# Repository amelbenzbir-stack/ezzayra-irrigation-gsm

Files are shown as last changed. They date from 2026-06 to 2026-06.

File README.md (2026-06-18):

# Ezzayra — Télégestion d'irrigation par SMS/GSM

> Stage d'ingénieur — Informatique Industrielle et Automatique (3e année, INSAT)
> **Entreprise :** EZZAYRA SOLUTIONS, Tunis
> **Étudiante :** Amal Ben Zbir
> **Durée :** 7 semaines — 2025-2026

---

## Contexte

EZZAYRA SOLUTIONS est une entreprise tunisienne spécialisée dans la digitalisation des chaînes de valeur agricoles. Sa plateforme **AgriManager** couvre la gestion parcellaire, le suivi satellitaire et le pilotage de l'irrigation pour plus de 60 000 hectares en Tunisie, Côte d'Ivoire et Espagne.

Sur le terrain, de nombreuses exploitations sont éloignées, sans couverture Internet fiable, mais couvertes par le réseau **GSM 2G**. Ce projet vise à concevoir un système embarqué autonome permettant de commander à distance, par simple SMS, les équipements d'irrigation d'une exploitation agricole.

---

## Objectif du projet

Concevoir, développer et tester un prototype fonctionnel de **carte de commande à distance** comprenant :

- Un microcontrôleur **Arduino Mega 2560** (prototype V1)
- Un module relais (4 canaux pour les électrovannes + 1 canal dédié à la motopompe)
- Un **modem GSM SIM800L** pour la réception et l'envoi de SMS
- Un afficheur **LCD 16x2** pour le diagnostic local sur site
- Un **firmware robuste** implémentant un protocole de commandes SMS sécurisé, avec programmation horaire automatique et alertes

---

## Architecture du système

```
Agriculteur (SMS)
      │
      ▼
Réseau GSM 2G
      │
      ▼
Modem SIM800L ──(UART)──► Arduino Mega 2560 ──► LCD 16x2 (diagnostic local)
                                │
                           GPIO (5V logique)
                                │
                      Modules relais (4 + 1 canaux)
                      /        |        \         \
                 Vanne 1   Vanne 2..4   Motopompe
                 (12/24V)   (12/24V)    (220V via contacteur)
```

---

## Protocole de commandes SMS

| Commande SMS | Action | Réponse |
|---|---|---|
| `#OUVRIR Vx` | Ouvrir l'électrovanne n°x (1 à 4) | `Vanne x ouverte - hh:mm:ss` |
| `#FERMER Vx` | Fermer l'électrovanne n°x | `Vanne x fermee - hh:mm:ss` |
| `#POMPE ON` | Démarrer la motopompe | `Pompe demarree - hh:mm:ss` |
| `#POMPE OFF` | Arrêter la motopompe | `Pompe arretee - hh:mm:ss` |
| `#PROG Vx hh:mm durée` | Planifier l'ouverture automatique d'une vanne | Confirmation + déclenchement/fermeture automatiques à l'heure prévue |
| `#PROG Vx OFF` | Annuler une programmation existante | `Programmation Vx annulee` |
| `#ETAT` | Rapport d'état complet | Vannes, pompe, signal GSM, programmations actives, horodatage |
| `#STOP` puis `#STOP CONFIRM` | Arrêt d'urgence à double confirmation (60s) | `ARRET URGENCE execute` |
| `#AIDE` | Liste des commandes disponibles | Liste complète |

---

## Fonctionnalités de sécurité

- **Liste blanche** : seuls les numéros pré-enregistrés peuvent commander le système ; toute autre tentative est ignorée et journalisée
- **État sûr au démarrage** : au redémarrage, toutes les sorties sont mises à l'état fermé
- **Watchdog logiciel** : réinitialisation automatique en cas de blocage supérieur à 30 secondes
- **Arrêt d'urgence à double confirmation** : la commande `#STOP` exige une confirmation explicite dans les 60 secondes
- **Protection pompe** : arrêt automatique après 1 heure de fonctionnement continu, avec alerte
- **Alerte signal GSM faible** : vérification périodique (10 min) du niveau de signal réseau
- **Isolation galvanique** : relais opto-isolés séparant la logique de commande des circuits de puissance

---

## Stack technique

| Composant | Technologie |
|---|---|
| Microcontrôleur | Arduino Mega 2560 (C/C++) |
| Communication GSM | SIM800L — commandes AT (`AT+CMGF`, `AT+CCLK?`, `AT+CSQ`...) |
| Affichage local | LCD 16x2 (bus 4 bits) |
| Simulation matérielle | Proteus 8 Professional |
| Schémas électriques | KiCad |
| Versioning | Git / GitHub |

---

## Structure du dépôt

```
ezzayra-irrigation-gsm/
├── firmware/
│   └── firmware_proteus.ino   ← Firmware complet (FSM, #PROG, LCD, sécurité)
│                                  Bascule production/démo via la constante
│                                  MODE_DEMO en tête de fichier :
│                                    - false → mode réel (Serial1 + modem SIM800L)
│                                    - true  → mode démonstration (lecture clavier
│                                              directe sur Serial + horloge simulée
│                                              accélérée, utilisé pour la vidéo)
├── simulation/
│   ├── simulation_ezzayra.pdsprj   ← Projet de simulation Proteus complet
│   └── firmware_proteus.ino.hex    ← Firmware compilé chargé dans la simulation
├── schemas/                    ← Schémas électriques KiCad
├── docs/
│   ├── Cahier_des_charges_v2.pdf
│   └── BOM_Ezzayra.pdf
└── README.md
```

---

## Mode de démonstration (simulation Proteus)

Le firmware intègre un **mode démonstration** activable par une simple constante (`MODE_DEMO`), pensé pour permettre une démonstration fluide et fiable du système sans dépendre d'un pont logiciel externe entre un modem GSM simulé et Proteus :

- Les commandes sont saisies directement dans le moniteur série Arduino (`Serial`), comme si elles étaient déjà des SMS décodés (ex. taper `#OUVRIR V1` directement)
- Une **horloge simulée accélérée** (1 minute simulée toutes les 3 secondes réelles) permet de démontrer la programmation horaire automatique (`#PROG`) sans attendre une vraie journée
- La commande `#HEURE hh:mm` permet de forcer l'horloge simulée à une valeur précise, utile pour caler une démonstration filmée

Cette approche a été retenue après plusieurs tentatives de pont série entre un simulateur externe et Proteus (COMPIM, ports série virtuels, automatisation de saisie), qui n'ont pas abouti à une solution suffisamment fiable pour une démonstration filmée.

---

## Planning du stage

| Phase | Contenu | Durée |
|---|---|---|
| P1 | Étude bibliographique, commandes AT, état de l'art | Semaine 1 |
| P2 | Conception schéma électrique, protocole SMS, BOM | Semaines 2-3 |
| P3 | Développement firmware C++ (FSM, relais, watchdog, #PROG) | Semaines 3-5 |
| P4 | Simulation Proteus, tests unitaires et de robustesse | Semaine 6 |
| P5 | Rapport, documentation, démonstration vidéo | Semaine 7 |

---

## Livrables

- [x] Cahier des charges et étude comparative des plateformes
- [x] Schéma électrique complet (KiCad) + BOM avec coûts
- [x] Firmware C++ commenté et versionné (commandes complètes + `#PROG` fonctionnel)
- [x] Simulation Proteus complète (relais, LCD, mode démonstration)
- [ ] Rapport de tests formalisé (scénario validé, mise en fichier en cours)
- [ ] Manuel d'installation destiné à l'agriculteur
- [ ] Rapport de stage complet
- [ ] Vidéo de démonstration

---

## Tester la simulation

### Prérequis
- Proteus 8 Professional
- Bibliothèque de modules relais Arduino installée (LIB + MODELS)

### Lancer la simulation
1. Ouvrir `simulation/simulation_ezzayra.pdsprj` dans Proteus
2. Lancer la simulation (▶)
3. Ouvrir le Virtual Terminal connecté sur Serial0
4. Taper directement une commande, par exemple `#OUVRIR V1`, puis Entrée

### Tester la programmation horaire automatique
```
#HEURE 06:25
#PROG V1 06:30 2
```
Puis observer le LCD : la vanne s'ouvre automatiquement à l'heure simulée programmée, et se referme après la durée prévue, sans intervention supplémentaire.

---

## Encadrement

- **Entreprise :** EZZAYRA SOLUTIONS — Tunis
- **Encadrant technique :** M. Yasser Bououd (CEO)
- **Encadrant académique :** INSAT — Informatique Industrielle et Automatique

---

*Stage réalisé dans le cadre de l'écosystème AgriManager — EZZAYRA SOLUTIONS, Tunis, 2025-2026*

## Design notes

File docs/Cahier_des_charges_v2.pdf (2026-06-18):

EZZAYRA SOLUTIONS

Tunis, Tunisie

Document technique interne — EZZAYRA SOLUTIONS

## CAHIER DES CHARGES

## Système de Télégestion de l’Irrigation Agricole

## par Commandes SMS sur Réseau GSM

Projet intégré à la plateforme AgriManager — EZZAYRA SOLUTIONS

Préparé par : | Amal Ben Zbir
Formation : | Ingénieure 3e année — INSAT Tunis
Spécialité : | Informatique Industrielle et Automatique
Encadrant : | M. Yasser Bououd, CEO
Durée : | 7 semaines

Année universitaire : 2025 – 2026

Date : | Juin 2026

EZZAYRA SOLUTIONS — Juin 2026

# Table des Matières

Introduction Générale | 3
1 Contexte Général et Analyse de la Problématique | 4
2 Objectifs, Périmètre et Parties Prenantes | 6
3 Exigences du Système | 8
4 Architecture Technique du Système | 11
5 Protocole de Communication SMS | 15
6 Plan de Réalisation et Livrables | 17
Conclusion Générale | 19

# Liste des Figures

4.1 Architecture fonctionnelle du système de télégestion par SMS/GSM . . 12

# Liste des Tableaux

2.1 Objectifs spécifiques du projet | | 6
2.2 Parties prenantes du projet | | 7
3.1 Exigences fonctionnelles | | 8
3.2 Exigences de sécurité | | 9
3.3 Exigences non fonctionnelles | | 10
4.1 Comparaison des plateformes microcontrôleurs | | 11
4.2 Description des blocs fonctionnels | | 13
4.3 États de la machine à états finis du firmware | | 14
5.1 Protocole de commandes SMS | | 16
5.2 Alertes automatiques | | 16
6.1 Planning prévisionnel du stage | | 17
6.2 Liste des livrables | | 18
6.3 Critères de validation du projet | | 18

# Introduction Générale

L’agriculture tunisienne traverse une phase de mutation profonde, portée par l’essor des technologies numériques et la nécessité d’optimiser l’utilisation des ressources naturelles, notamment l’eau. Dans ce contexte, la gestion intelligente de l’irrigation représente un levier stratégique pour améliorer la productivité agricole et réduire les coûts d’exploitation.

Ce document constitue le cahier des charges du projet mené au sein de la société EZZAYRA SOLUTIONS, acteur tunisien de l’agriculture numérique. Le projet vise à concevoir un dispositif électronique embarqué permettant la commande à distance d’équipements d’irrigation par simple message SMS, en s’appuyant uniquement sur l’infrastructure GSM 2G disponible dans les zones rurales.

Le présent cahier des charges a pour objectifs de définir rigoureusement les besoins du système, de préciser les contraintes techniques et opérationnelles, de justifier les choix d’architecture et de fournir un cadre de référence pour l’ensemble des phases de réalisation.

Ce document est structuré en six chapitres :

- Chapitre 1 — Contexte général et analyse de la problématique
- Chapitre 2 — Objectifs, périmètre et parties prenantes
- Chapitre 3 — Exigences fonctionnelles et non fonctionnelles
- Chapitre 4 — Architecture technique du système
- Chapitre 5 — Protocole de communication SMS
- Chapitre 6 — Plan de réalisation, livrables et validation

## Chapitre 1

# Contexte Général et Analyse de la Problématique

### 1.1 Présentation de l’entreprise EZZAYRA SOLUTIONS

EZZAYRA SOLUTIONS est une entreprise tunisienne spécialisée dans les solutions numériques pour l’agriculture. Elle développe la plateforme AgriManager, déployée sur plus de 60 000 hectares en Tunisie, en Côte d’Ivoire et en Espagne, couvrant la gestion des parcelles, la planification agricole et le pilotage de l’irrigation.

### 1.2 Diagnostic de la situation actuelle

L’analyse des pratiques d’irrigation sur les exploitations agricoles tunisiennes, en particulier dans les régions centre et sud, révèle plusieurs dysfonctionnements récurrents liés à l’absence de systèmes de commande à distance.

Les exploitations concernées se caractérisent par leur éloignement géographique, l’absence de connexion Internet stable et la dépendance totale à des interventions physiques pour toute opération sur les équipements d’irrigation. Cette réalité engendre des surcoûts significatifs en termes de déplacements, une réactivité insuffisante en cas d’anomalie et une gestion approximative des plages d’arrosage.

### 1.3 Problématique

Comment concevoir un système embarqué autonome permettant à un agriculteur de piloter ses équipements d’irrigation depuis son téléphone mobile, sans nécessiter de connexion Internet, tout en garantissant la sécurité, la fiabilité et la simplicité d’utilisation du dispositif ?

### 1.4 Solution envisagée

Cahier des Charges — Carte de commande GSM/SMS INSAT / EZZAYRA SOLUTIONS

La solution proposée repose sur le réseau GSM 2G, dont la couverture est quasi-totale sur le territoire tunisien, y compris dans les zones rurales isolées. Une carte électronique embarquée, installée sur le site agricole, assurera la réception de commandes transmises par SMS, leur traitement sécurisé et l’activation des actionneurs correspondants. Chaque commande donnera lieu à un accusé de réception automatique, et le système sera capable d’émettre des alertes en cas d’anomalie.

EZZAYRA SOLUTIONS | 2025–2026 | 5

## Chapitre 2

# Objectifs, Périmètre et Parties Prenantes

### 2.1 Objectif général

Concevoir, développer et valider un prototype fonctionnel d’un système de télégestion de l’irrigation par SMS/GSM, destiné à être intégré à la plateforme AgriManager d’EZZAYRA SOLUTIONS dans une phase ultérieure.

### 2.2 Objectifs spécifiques

Table 2.1: Objectifs spécifiques du projet

Réf. | Objectif | Détail
OS-1 | Étude et analyse | Étudier les solutions existantes et établir un état de l’art
OS-2 | Conception matérielle | Produire le schéma électrique complet sous KiCad
OS-3 | Développement firmware | Implémenter le firmware en C++ sur microcontrôleur Arduino
OS-4 | Protocole SMS | Définir et implémenter un protocole de commandes sécurisé
OS-5 | Simulation | Valider le système en environnement de simulation Proteus, avec un mode de démonstration intégré au firmware
OS-6 | Tests | Réaliser les tests unitaires et de robustesse du système
OS-7 | Documentation | Produire l’ensemble des livrables techniques et documentaires

### 2.3 Périmètre du projet

### 2.3.1 Inclus dans le périmètre

- Schéma électrique complet (alimentation, protection, isolation, commande)
- Firmware Arduino Mega 2560 avec machine à états et protocole SMS
- Simulation Proteus du circuit complet (microcontrôleur, modules relais, LCD) avec mode de démonstration intégré au firmware pour la validation fonctionnelle
- Tests fonctionnels et de robustesse
- Documentation : cahier des charges, BOM, manuel utilisateur, rapport de stage

### 2.3.2 Hors périmètre

- Intégration à la plateforme AgriManager (phase ultérieure)
- Application mobile dédiée
- Communication via réseau 4G ou Internet

### 2.4 Parties prenantes

Table 2.2: Parties prenantes du projet

Partie prenante | Rôle | Intérêt
Amal Ben Zbir | Étudiante / Développeuse | Réalisation du projet de stage
M. Yasser Bououd | Encadrant entreprise / CEO | Validation technique et fonctionnelle
Encadrant INSAT | Encadrant académique | Suivi pédagogique et évaluation
Agriculteurs | Utilisateurs finaux | Utilisation quotidienne du système
EZZAYRA SOLUTIONS | Commanditaire | Intégration future à AgriManager

## Chapitre 3

# Exigences du Système

### 3.1 Exigences fonctionnelles

Table 3.1: Exigences fonctionnelles

ID | Intitulé | Description | Prior.
EF-01 | Réception SMS | Décoder les messages SMS entrants via le modem SIM800L | P1
EF-02 | Commande vannes | Ouvrir et fermer indépendamment jusqu’à 4 électrovannes | P1
EF-03 | Commande pompe | Démarrer et arrêter la motopompe | P1
EF-04 | Accusé de réception | Envoyer un SMS de confirmation après chaque commande | P1
EF-05 | Rapport d’état | Fournir l’état complet des sorties, le signal GSM et l’horodatage | P1
EF-06 | Arrêt d’urgence | Couper toutes les sorties en réponse à la commande #STOP | P1
EF-07 | Horodatage | Inclure la date et l’heure dans chaque réponse SMS | P2
EF-08 | Programmation | Planifier l’ouverture d’une vanne à une heure donnée | P2
EF-09 | Alerte démarrage | Notifier les numéros autorisés lors de chaque redémarrage | P1
EF-10 | Protection pompe | Arrêter la pompe et alerter après dépassement de la durée maximale | P1
EF-11 | Alerte GSM | Signaler un niveau de signal GSM insuffisant | P2
EF-12 | Aide utilisateur | Retourner la liste des commandes disponibles sur demande | P3
P1 : Prioritaire | P2 : Souhaitable | P3 : Optionnel

Note relative à EF-08 (programmation horaire) : la précision du déclenchement dépend de la fréquence d’interrogation de l’horloge réseau GSM par le firmware (60 secondes), ce qui induit un écart possible de l’ordre de ±1 minute par rapport à l’heure programmée. Cette limite, acceptable pour un usage agricole, sera levée en V2 par l’ajout d’un module RTC externe DS3231 garantissant une précision à la seconde, indépendante du réseau GSM.

### 3.2 Exigences de sécurité

Table 3.2: Exigences de sécurité

ID | Intitulé | Description
ES-01 | Contrôle d’accès | Seuls les numéros de téléphone pré-enregistrés peuvent envoyer des commandes
ES-02 | Rejet des intrus | Toute commande d’un numéro non autorisé est ignorée sans réponse
ES-03 | Journalisation | Les tentatives non autorisées sont comptabilisées et signalées à l’administrateur
ES-04 | État sûr au démarrage | Au démarrage ou après toute réinitialisation, toutes les sorties sont à l’état fermé
ES-05 | Double confirmation | La commande d’arrêt d’urgence requiert une confirmation explicite dans les 60 secondes
ES-06 | Surveillance système | Un mécanisme de watchdog détecte et corrige tout blocage du programme
ES-07 | Protection électrique | Une diode de protection prévient les dommages en cas d’inversion de polarité
ES-08 | Isolation galvanique | Les relais opto-isolés séparent physiquement la logique de commande et les circuits de puissance

### 3.3 Exigences non fonctionnelles

Table 3.3: Exigences non fonctionnelles

ID | Catégorie | Description
ENF-01 | Performance | Le délai entre la réception du SMS et l’exécution de la commande ne doit pas excéder 10 secondes
ENF-02 | Disponibilité | Le système doit fonctionner de manière continue, 24h/24 et 7j/7, sans intervention humaine
ENF-03 | Alimentation | L’alimentation principale est de 12 V DC, compatible batterie et panneau solaire
ENF-04 | Consommation | La consommation en veille doit être inférieure à 200 mA pour permettre une alimentation solaire
ENF-05 | Température | Le système doit fonctionner correctement entre −10 ◦C et +60 ◦C
ENF-06 | Protection | L’installation doit être réalisée dans un boîtier étanche de classe IP65 minimum
ENF-07 | Maintenabilité | Le code source doit être commenté, structuré et versionné sur un dépôt Git
ENF-08 | Coût | Le coût total en composants ne doit pas excéder 250 DT hors option solaire
ENF-09 | Connectivité | Le système doit opérer uniquement via le réseau GSM 2G, sans dépendance à Internet
ENF-10 | Fiabilité | Le taux de succès de traitement des commandes SMS valides doit dépasser 99 %

## Chapitre 4

# Architecture Technique du Système

### 4.1 Étude comparative des plateformes microcontrôleurs

Trois familles de microcontrôleurs ont été évaluées selon des critères adaptés aux contraintes du projet : déploiement sur site isolé, alimentation autonome, développement rapide et fiabilité à long terme.

Table 4.1: Comparaison des plateformes microcontrôleurs

Critère | Arduino Mega 2560 | STM32 Nucleo | Raspberry Pi 4
Démarrage | Immédiat | Immédiat | 25–35 s (OS)
Consommation veille | ≈50 mA | ≈30 mA | ≈600 mA
Complexité dev. | Faible | Moyenne | Élevée
Fiabilité terrain | Très bonne | Excellente | Moyenne
Ports UART | 4 matériels | 3 matériels | 1 matériel
Écosystème | Très large | Large | Large
Coût approximatif | 63 DT | 135 DT | 250 DT
Verdict | Prototype V1 | V2 industrielle | Non retenu

L’Arduino Mega 2560 est sélectionné pour le prototype V1 au regard de quatre facteurs déterminants : son démarrage instantané sans système d’exploitation, sa consommation faible compatible avec une alimentation solaire, ses quatre ports UART matériels facilitant la communication avec le modem GSM, et son coût sensiblement inférieur aux alternatives.

### 4.2 Architecture matérielle

### 4.2.1 Schéma fonctionnel du système

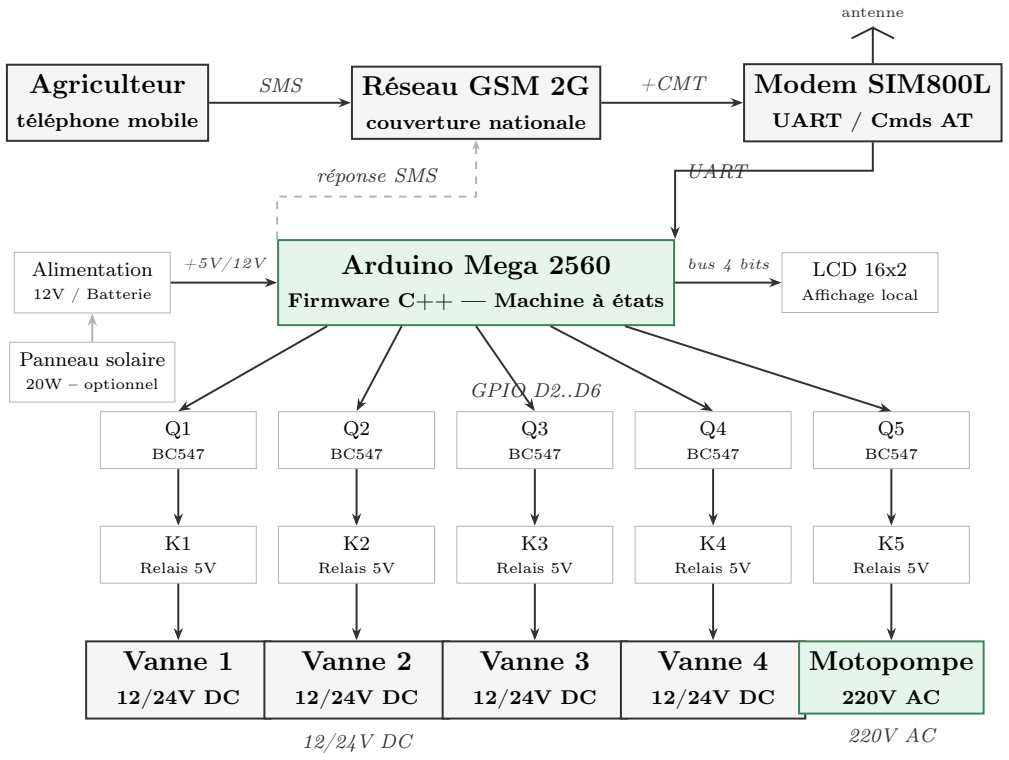
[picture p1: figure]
Agriculteur; téléphone mobile; Réseau GSM 2G; couverture nationale; Modem SIM800L; UART / Cmds AT; antenne; SMS; +CMT; Arduino Mega 2560; Firmware C++ — Machine à états; réponse SMS; UART; Alimentation; 12V / Batterie; Panneau solaire; 20W – optionnel; LCD 16x2; Affichage local; bus 4 bits; GPIO D2..D6; Relais 5V; Vanne 1; Vanne 2; Vanne 3; Vanne 4; Motopompe

Figure 4.1: Architecture fonctionnelle du système de télégestion par SMS/GSM

### 4.2.2 Description des blocs fonctionnels

Table 4.2: Description des blocs fonctionnels

Bloc | Composant | Fonction
Microcontrôleur | Arduino Mega 2560 | Cerveau du système : interprète les commandes SMS, pilote les sorties et assure la sécurité via une machine à états finis
Modem GSM | SIM800L V2.0 | Émission et réception de SMS via le réseau GSM 2G. Fournit l’heure réseau via la commande AT AT+CCLK?
Horodatage | AT+CCLK? (SIM800L) | L’heure est extraite du réseau GSM via la commande AT AT+CCLK? du modem. Cette approche est suffisante pour le prototype V1. L’ajout d’un module RTC externe DS3231 est prévu en V2 pour garantir l’horodatage lors des coupures réseau
Régulation 5 V | L7805 + C 1000 µF | Régulateur linéaire 12 V → 5 V pour le prototype V1. Le condensateur 1000 µF en sortie absorbe les pics de courant du SIM800L (jusqu’à 2 A sur de courtes durées). Pour la version industrielle V2, un convertisseur DC-DC Buck LM2596 (3 A, rendement 90 %) sera préféré pour réduire l’échauffement
Adaptation niveaux | Diviseur R6/R7 | Conversion 5 V → 3,3 V sur la ligne TX Arduino → SIM800L
Drivers transistors | BC547 + 1 kΩ (x5) | Amplification du signal GPIO (5 mA) pour commander les bobines des relais (100 mA)
Relais | G5V-2 5 V (x5) | Isolation galvanique entre logique 5 V et circuits de puissance (12/24 V DC – 220 V AC)
Protection entrée | Diode 1N4007 | Protection contre l’inversion de polarité à l’entrée 12 V
Affichage local | LCD 16x2 | Affichage en temps réel de l’état des vannes, de la pompe, des alertes et de l’heure réseau, pour la maintenance et le diagnostic sur site

### 4.3 Architecture logicielle

Le firmware est construit autour d’une machine à états finis (FSM) qui garantit un comportement déterministe et une gestion robuste des cas limites.

Table 4.3: États de la machine à états finis du firmware

État | Désignation | Comportement
S0 | VEILLE | Surveillance permanente du port série GSM en attente d’un événement
S1 | SMS_RECU | Détection d’une notification +CMT et lecture du contenu du message
S2 | VERIFICATION | Contrôle du numéro expéditeur par rapport à la liste blanche
S3 | EXECUTION | Interprétation et exécution de la commande reçue
S4 | REPONSE | Envoi du SMS de confirmation horodaté à l’expéditeur
S5 | ALERTE | Émission d’un SMS d’alerte automatique vers les numéros autorisés

## Chapitre 5

# Protocole de Communication SMS

### 5.1 Format général des commandes

L’ensemble des commandes respecte la syntaxe suivante :

#<COMMANDE> [PARAMÈTRE1] [PARAMÈTRE2]

Les commandes sont insensibles à la casse et converties en majuscules avant traitement. Tout message ne respectant pas ce format est ignoré et journalisé.

### 5.2 Tableau des commandes SMS

Table 5.1: Protocole de commandes SMS

Commande | Action déclenchée | Réponse SMS
#OUVRIR Vx | Ouverture de la vanne x | Vanne x ouverte –-hh:mm:ss

#FERMER Vx | Fermeture de la vanne x | Vanne x fermee –-hh:mm:ss

#POMPE ON | Démarrage de la pompe | Pompe demarree –-hh:mm:ss

#POMPE OFF | Arrêt de la pompe | Pompe arretee –-hh:mm:ss

#ETAT | Rapport d’état du système | État V1..V4, pompe, signal GSM, heure

#PROG Vx hh:mm dur | Ouverture planifiée d’une vanne | Prog Vx enregistree – OK

#PROG Vx OFF | Annulation d’une programmation existante | Programmation Vx annulee

#STOP | Demande d’arrêt d’urgence | Confirmez avec #STOP CONFIRM

#STOP CONFIRM | Arrêt d’urgence confirmé | ARRET URGENCE execute –-hh:mm:ss

#AIDE | Liste des commandes | Liste complète par SMS

### 5.3 Alertes automatiques du système

Table 5.2: Alertes automatiques

Événement | Message SMS envoyé
Redémarrage du système | Notification de remise en service et confirmation de l’état sûr
Durée maximale pompe atteinte | Alerte arrêt automatique avec horodatage
Signal GSM faible (CSQ < 10) | Alerte avec niveau de signal mesuré
3 tentatives non autorisées | Alerte sécurité avec numéro de l’expéditeur suspect

## Chapitre 6

# Plan de Réalisation et Livrables

### 6.1 Planning prévisionnel

Table 6.1: Planning prévisionnel du stage

Phase | Intitulé | Tâches principales | Durée
P1 | Étude et état de l’art | Analyse de l’existant, commandes AT GSM, documentation | S1
P2 | Conception | Schéma KiCad, nomenclature BOM, protocole SMS | S2–S3
P3 | Développement firmware | FSM, commandes AT, relais, watchdog | S3–S5
P4 | Tests et simulation | Simulation Proteus, tests unitaires, tests de robustesse | S6
P5 | Documentation | Rapport, manuel utilisateur, démonstration | S7

### 6.2 Livrables du projet

Table 6.2: Liste des livrables

N° | Livrable | Description | Phase
L1 | Cahier des charges | Document de référence du projet (présent document) | P1
L2 | Schéma électrique | Fichier KiCad complet exporté en PDF | P2
L3 | BOM | Nomenclature avec références et prix en DT | P2
L4 | Firmware C++ | Code source commenté et versionné sur GitHub | P3
L5 | Simulation Proteus | Schéma de simulation complet et mode de démonstration intégré au firmware | P4
L6 | Rapport de tests | Résultats des tests unitaires et de robustesse | P4
L7 | Manuel utilisateur | Guide simplifié destiné à l’agriculteur | P5
L8 | Rapport de stage | Document final complet | P5

### 6.3 Critères d’acceptation

Table 6.3: Critères de validation du projet

ID | Critère | Condition de validation
CA-01 | Délai de traitement | Inférieur à 10 secondes entre la réception du SMS et l’exécution
CA-02 | Contrôle d’accès | 100 % des commandes non autorisées rejetées sans réponse
CA-03 | Résilience | Redémarrage en état sûr après toute coupure d’alimentation
CA-04 | Watchdog | Réinitialisation automatique en cas de blocage supérieur à 30 secondes
CA-05 | Protection pompe | Arrêt automatique après 1 heure de fonctionnement continu
CA-06 | Accusés de réception | 100 % des commandes valides génèrent un SMS de confirmation
CA-07 | Couverture fonctionnelle | Les 9 commandes du protocole fonctionnent sans erreur

# Conclusion Générale

Ce cahier des charges a permis de formaliser l’ensemble des aspects du projet de télégestion de l’irrigation agricole par SMS/GSM mené au sein d’EZZAYRA SOLUTIONS dans le cadre du stage de fin de 3e année à l’INSAT.

L’analyse de la situation de départ a mis en évidence un besoin concret et pertinent : permettre aux agriculteurs d’exploitations isolées de piloter leurs équipements d’irrigation à distance, sans nécessiter de connexion Internet, à partir de leur téléphone mobile ordinaire. La solution retenue, basée sur un Arduino Mega 2560 couplé à un modem SIM800L et un réseau de relais opto-isolés, répond de manière adaptée à l’ensemble des contraintes identifiées.

Les exigences fonctionnelles, de sécurité et non fonctionnelles ont été rigoureusement définies, et les critères d’acceptation établis permettront une validation objective du système à l’issue de la phase de tests. Ce document servira de référence commune entre l’étudiante, l’encadrant industriel et l’encadrant académique tout au long de la réalisation du projet.

La réussite de ce projet ouvrira la voie à une intégration du module de commande au sein de la plateforme AgriManager, contribuant ainsi à la stratégie de digitalisation de l’agriculture tunisienne portée par EZZAYRA SOLUTIONS.

Évolutions envisagées pour la version V2 : le choix de l’Arduino Mega 2560, doté de quatre ports UART matériels, permettra de remplacer facilement le modem SIM800L (GSM 2G) par un module SIM7600 (4G/LTE) sans réécriture du firmware, anticipant ainsi l’obsolescence progressive du réseau 2G. Par ailleurs, le renforcement de la sécurité par l’ajout d’un code PIN dans les commandes SMS (exemple : #OUVRIR V1 1234) permettra de prévenir les risques d’usurpation d’identité, pour une utilisation en environnement industriel sensible.

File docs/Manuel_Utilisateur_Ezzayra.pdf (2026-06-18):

Manuel d'utilisation — Système EZZAYRA

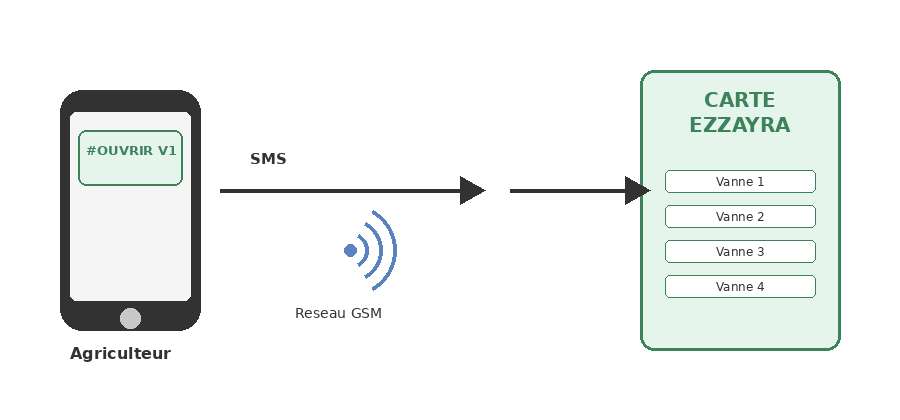
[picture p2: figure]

EZZAYRA SOLUTIONS — Page 1

## EZZAYRA SOLUTIONS

Tunis, Tunisie

# MANUEL D'UTILISATION

## Système de commande d'irrigation par SMS

Guide simple pour piloter vos vannes et votre pompe depuis votre téléphone

EZZAYRA SOLUTIONS — Page 2

## Bienvenue

Ce guide vous explique, de façon simple, comment commander vos vannes d'irrigation et votre pompe à l'aide de votre téléphone portable, par simple message (SMS).
Vous n'avez besoin d'aucune connexion Internet. Le système fonctionne avec le réseau de téléphone mobile classique, le même que celui que vous utilisez pour appeler ou envoyer des SMS.
Vous pouvez, depuis n'importe où :
- Ouvrir ou fermer chacune de vos 4 vannes d'irrigation
- Démarrer ou arrêter votre pompe
- Programmer un arrosage automatique à une heure précise
- Connaître à tout moment l'état de votre installation

À chaque message que vous envoyez, le système vous répond par SMS pour confirmer ce qu'il a fait.

## Comment ça marche

Vous envoyez un SMS avec une commande précise (par exemple « ouvrir la vanne 1 ») à partir de votre téléphone, vers le numéro de la carte installée sur votre exploitation. Quelques secondes plus tard, la carte exécute votre demande et vous renvoie un SMS de confirmation.

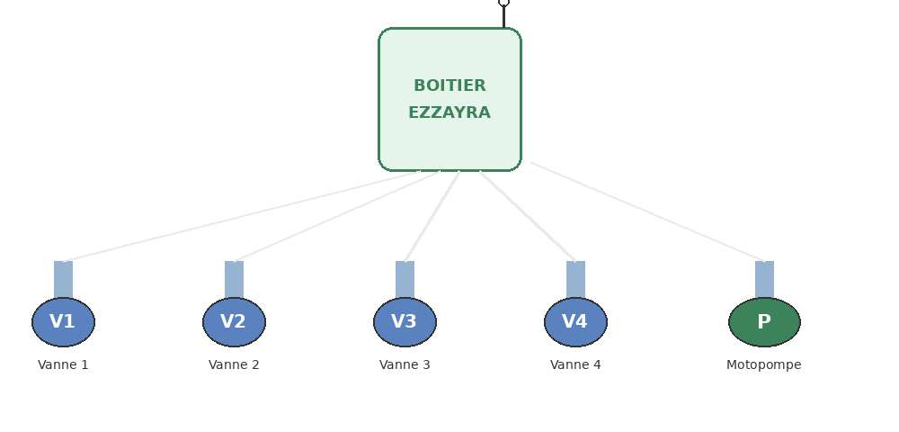
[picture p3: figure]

EZZAYRA SOLUTIONS — Page 3

Voici les éléments de votre installation :

Votre installation comprend 4 vannes (V1 à V4) pour vos différentes parcelles ou zones d'arrosage, et une motopompe pour faire circuler l'eau.

## Les commandes que vous pouvez envoyer

Important : écrivez la commande exactement comme indiqué ci-dessous, avec le symbole # au début. Les majuscules ou minuscules n'ont pas d'importance.

Ouvrir une vanne

#OUVRIR V1 | Ouvre la vanne numéro 1. Remplacez le chiffre par 2, 3 ou 4 pour les autres vannes.

Réponse reçue : | Vanne 1 ouverte - 14:32:05

Fermer une vanne

#FERMER V1 | Ferme la vanne numéro 1.

Réponse reçue : | Vanne 1 fermee - 14:45:10

Démarrer la pompe

#POMPE ON | Démarre la motopompe.

Réponse reçue : | Pompe demarree - 14:50:00

Arrêter la pompe

#POMPE OFF | Arrête la motopompe.

Réponse reçue : | Pompe arretee - 15:30:00

EZZAYRA SOLUTIONS — Page 4

Programmer un arrosage automatique

#PROG V1 06:30 20 | Programme l'ouverture automatique de la vanne 1 chaque jour à 6h30, pendant 20 minutes. La vanne se fermera ensuite toute seule.

Réponse reçue : | Prog V1 enregistree a 06:30 duree 20min - OK
Vous pouvez remplacer 06:30 par l'heure de votre choix, et 20 par le nombre de minutes que vous souhaitez.

Annuler une programmation

#PROG V1 OFF | Annule la programmation automatique de la vanne 1.

Réponse reçue : | Programmation V1 annulee

Connaître l'état de votre installation

#ETAT | Vous indique si chaque vanne est ouverte ou fermée, si la pompe fonctionne, et la qualité du réseau.

Réponse reçue : | ETAT SYSTEME : V1 FERMEE, V2 FERMEE... Signal:22/31

Voir la liste des commandes

#AIDE | Le système vous renvoie la liste complète des commandes disponibles, en cas d'oubli.

Réponse reçue : | Liste des commandes par SMS

## En cas d'urgence : tout arrêter

Si vous devez arrêter immédiatement toute votre installation (toutes les vannes et la pompe), procédez en deux étapes, pour éviter qu'un message envoyé par erreur n'arrête tout sans le vouloir.
Étape 1
#STOP | Demande l'arrêt d'urgence. Le système attend votre confirmation.

Réponse reçue : | ATTENTION: tapez #STOP CONFIRM dans 60s

Étape 2 — dans la minute qui suit

#STOP CONFIRM | Confirme l'arrêt d'urgence. Toutes les vannes et la pompe s'arrêtent immédiatement.

Réponse reçue : | ARRET URGENCE execute - 16:02:11
Si vous ne confirmez pas dans la minute, l'arrêt d'urgence est annulé et rien ne se passe — vous devrez recommencer depuis l'étape 1 si besoin.

EZZAYRA SOLUTIONS — Page 5

## Sécurité de votre installation

Seuls les numéros autorisés peuvent commander le système
Votre installation ne répond qu'aux numéros de téléphone que vous avez enregistrés au préalable auprès d'EZZAYRA SOLUTIONS. Si quelqu'un d'autre essaie d'envoyer une commande depuis un numéro non autorisé, le système l'ignore complètement et ne fait rien.

Votre installation se met en sécurité au démarrage
À chaque redémarrage (par exemple après une coupure de courant), toutes les vannes et la pompe sont automatiquement remises à l'état fermé, pour éviter tout arrosage accidentel.

La pompe s'arrête seule après 1 heure
Si vous oubliez d'arrêter la pompe, elle s'arrête automatiquement après une heure de fonctionnement continu, et vous recevez un SMS pour vous en informer.

## Questions fréquentes

Je n'ai reçu aucune réponse après ma commande, que faire ?
Vérifiez d'abord que vous avez bien écrit la commande exactement comme indiqué dans ce guide, avec le symbole #. Si le problème persiste, vérifiez que vous êtes dans une zone correctement couverte par le réseau mobile, et réessayez après quelques minutes. Le système me dit que le signal est faible, est-ce grave ?
Cela signifie que la couverture du réseau mobile à l'endroit où est installée votre carte est faible. Cela ne l'empêche pas de fonctionner, mais les délais de réponse peuvent être plus longs. Si le signal reste faible durablement, contactez EZZAYRA SOLUTIONS. Puis-je changer l'heure d'une programmation déjà enregistrée ?
Oui : envoyez simplement une nouvelle commande #PROG pour la même vanne avec la nouvelle heure. Elle remplace automatiquement l'ancienne programmation.
Que se passe-t-il en cas de coupure de courant ?
Au retour du courant, le système redémarre automatiquement et remet toutes les vannes et la pompe à l'état fermé, par sécurité. Vous devrez renvoyer vos commandes ou vos programmations si nécessaire.
Qui contacter en cas de problème ?
Contactez votre encadrant technique chez EZZAYRA SOLUTIONS, qui pourra vérifier l'installation à distance ou intervenir sur site si nécessaire.

EZZAYRA SOLUTIONS — Page 6

## Aide-mémoire à conserver

Vous pouvez imprimer cette page et la garder près de chez vous pour vous y référer rapidement.

Commande | Action
#OUVRIR Vx | Ouvre la vanne x (1 à 4)

#FERMER Vx | Ferme la vanne x (1 à 4)

#POMPE ON | Démarre la pompe

#POMPE OFF | Arrête la pompe

#PROG Vx hh:mm durée | Programme un arrosage automatique

#PROG Vx OFF | Annule une programmation

#ETAT | Affiche l'état complet de l'installation

#STOP puis #STOP CONFIRM | Arrête tout en cas d'urgence

#AIDE | Affiche la liste des commandes

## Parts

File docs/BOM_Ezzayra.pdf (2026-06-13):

EZZAYRA SOLUTIONS
Tunis, Tunisie
Juin 2026

## NOMENCLATURE DES COMPOSANTS

Projet : Carte de commande à distance d'électrovannes et motopompe via GSM/SMS Étudiant : Amal Ben Zbir

Réf. | Désignation | Qté | Référence | Fournisseur | Prix unit. (DT) | Prix total (DT)
U1 | Arduino Mega 2560 R3 (54 E/S, 256kB Flash) | 1 | ATmega2560 | Tuni-Smart-Innovation | 62.500 | 62.500
U2 | Module GSM/GPRS SIM800L V2.0 5V + antenne | 1 | SIM800L V2.0 | Tuni-Smart-Innovation | 43.900 | 43.900
U3 | Régulateur de tension L7805 (12V → 5V, 1A) | 1 | L7805CV TO-220 | Cothings | 1.500 | 1.500
U4 | Régulateur AMS1117-3.3 (5V → 3.3V, 800mA) | 1 | AMS1117-3.3 | Cothings | 1.200 | 1.200
K1–K5 | Module relais 1 canal 5V opto-isolé (x5) | 5 | SRD-05VDC-SL-C | Tuni-Smart-Innovation | 5.900 | 29.500
Q1–Q5 | Transistor NPN BC547 (x5) | 5 | BC547B TO-92 | Cothings | 0.300 | 1.500
D1 | Diode redresseur 1N4007 (protection polari.) | 1 | 1N4007 DO-41 | Cothings | 0.200 | 0.200
ANT | Antenne GSM câble 3M connecteur SMA | 1 | GSM-ANT-SMA-3M | Tuni-Smart-Innovation | 20.000 | 20.000
J1–J5 | Connecteur bornier à vis KF301 2 pins (x5) | 5 | KF301-2P 5mm | Cothings | 0.500 | 2.500
J6 | Connecteur alimentation bornier 2 pins | 1 | KF301-2P 5mm | Cothings | 0.500 | 0.500
R1–R5 | Résistance 1 kΩ 1/4W — base transistors (x5) | 5 | CF-1/4W-1K ±5% | Little Son | 0.050 | 0.250
R6 | Résistance 10 kΩ 1/4W — diviseur tension TX | 1 | CF-1/4W-10K ±5% | Little Son | 0.050 | 0.050
R7 | Résistance 20 kΩ 1/4W — diviseur tension TX | 1 | CF-1/4W-20K ±5% | Little Son | 0.050 | 0.050
C1, C3 | Condensateur céramique 100 nF / 50V (x2) | 2 | C100N-50V | Little Son | 0.150 | 0.300
C2, C4 | Condensateur électrolytique 10 µF / 25V (x2) | 2 | EC10U-25V | Little Son | 0.300 | 0.600
SIM | Carte SIM nano prépayée avec crédit SMS | 1 | Nano SIM | Tunisie Telecom | 8.000 | 8.000
BAT | Batterie plomb-acide 12V / 7Ah scellée AGM | 1 | 12V-7AH AGM | AliExpress | 45.000 | 45.000
SOL* | Panneau solaire 20W / 12V (option autonomie) | 1 | SP-20W-12V | AliExpress | 55.000 | 55.000

Réf. | Désignation | Qté | Référence | Fournisseur | Prix unit. (DT) | Prix total (DT)
PCB | Platine de prototypage perforée 20×15 cm | 1 | PCB-200×150 mm | AliExpress | 4.000 | 4.000
BOX | Boîtier étanche IP65 (200×150×75 mm) | 1 | IP65-ABS | AliExpress | 25.000 | 25.000
Total hors option solaire : | | | | | | 246.550 DT
Total avec option solaire (*) : | | | | | | 301.550 DT

Fournisseurs :
- Tuni-Smart-Innovation — 1 Rue Pierre Mendès France, Ariana 2080 — Tél. +216 51 954 443 — tuni-smart-innovation.com
- Cothings — cothings.net — Tél. +216 29 000 953 — contact@cothings.net
- Little Son — little-son.tn — Vente en ligne de composants électroniques en Tunisie
- AliExpress — aliexpress.com — Pour les composants passifs non disponibles localement
- Tunisie Telecom — Pour la carte SIM prépayée avec forfait SMS actif (Ooredoo accepté également) Notes :
1. Prix vérifiés en Juin 2026. Les prix peuvent varier selon la disponibilité des stocks.
2. (*) Le panneau solaire est optionnel — il permet une installation 100% autonome sur site isolé.
3. Les prix AliExpress sont estimatifs. Livraison non incluse (environ 10 à 15 DT selon transporteur).
4. Un module relais 4 canaux peut remplacer les 4 relais K1–K4 individuels si disponible chez le fournisseur.

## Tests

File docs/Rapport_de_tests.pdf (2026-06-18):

Rapport de Tests — Carte de commande GSM/SMS | INSAT / EZZAYRA SOLUTIONS
EZZAYRA SOLUTIONS | 2025-2026 | 1

## EZZAYRA SOLUTIONS

Tunis, Tunisie

Document technique interne — EZZAYRA SOLUTIONS

# RAPPORT DE TESTS

### Système de Télégestion de l'Irrigation Agricole par Commandes SMS sur Réseau GSM

Livrable L6 — Résultats des tests fonctionnels et de robustesse

Préparé par : | Amal Ben Zbir
Formation : | Ingénieure 3e année — INSAT Tunis
Spécialité : | Informatique Industrielle et Automatique
Encadrant : | M. Yasser Bououd, CEO
Environnement de test : | Simulation Proteus 8 Professional
Firmware testé : | firmware_proteus.ino (mode démonstration)
Date : | Juin 2026

EZZAYRA SOLUTIONS | 2025-2026 | 2

### 1. Objectif et méthodologie

Ce document présente les résultats des tests fonctionnels réalisés sur le système de télégestion d'irrigation par SMS/GSM, conformément aux exigences fonctionnelles (EF) et de sécurité (ES) définies dans le cahier des charges du projet.

Les tests ont été exécutés dans l'environnement de simulation Proteus 8 Professional, sur un schéma complet incluant l'Arduino Mega 2560, l'afficheur LCD 16x2, et les modules relais pilotant les quatre électrovannes et la motopompe. Le firmware utilisé intègre un mode de démonstration (constante MODE_DEMO) qui permet la saisie directe des commandes via le moniteur série, ainsi qu'une horloge simulée accélérée permettant de valider la programmation horaire automatique sans attendre une journée complète.

Chaque test est identifié par un code (Txx), associé à une commande SMS ou un scénario, un résultat attendu et le résultat observé lors de l'exécution. Les exigences correspondantes du cahier des charges sont indiquées entre parenthèses lorsque applicable.

### 2. Résultats des tests fonctionnels

Le tableau suivant synthétise l'ensemble des tests exécutés et leur résultat.

ID | Exig. | Commande / Scénario | Résultat attendu | Résultat observé | Statut
T01 | ES-04 | Démarrage du système | Toutes les sorties à l'état fermé, LCD affiche "Systeme pret" | Toutes sorties fermées confirmé dans le journal série ; LCD conforme | Validé
T02 | EF-02 | #OUVRIR V1 puis #FERMER V1 | Vanne 1 ouverte puis fermée, LED et LCD à jour | Vanne 1 OUVERTE puis FERMEE, confirmé visuellement (LED + contact relais) | Validé
T03 | ES-01 / ES-02 | Commande depuis un numéro non autorisé | Commande ignorée, aucune sortie affectée, tentative journalisée | Aucune action sur les sorties ; tentative comptabilisée dans le journal | Validé
T04 | EF-03 | #POMPE ON puis #POMPE OFF | Motopompe démarrée puis arrêtée, durée cumulée mise à jour | Pompe DEMARREE puis ARRETEE ; compteur de durée correct | Validé
T05 | ES-05 | #STOP puis #STOP CONFIRM | Confirmation demandée, arrêt total après confirmation dans les 60s | Message de confirmation affiché ; toutes sorties fermées après #STOP CONFIRM | Validé
T06 | EF-08 | #HEURE 06:25 puis #PROG V1 06:30 2 | Déclenchement automatique de la vanne à l'heure programmée, fermeture automatique après la durée prévue, sans intervention manuelle | Vanne 1 ouverte automatiquement à 06:30 (horloge simulée), fermée automatiquement après 2 min simulées | Validé
T07 | EF-08 | #PROG V1 OFF | Annulation de la programmation, plus aucun déclenchement automatique ultérieur | Message "Programmation V1 annulee" confirmé ; | Validé

EZZAYRA SOLUTIONS | 2025-2026 | 3
| | | | aucun redéclenchement observé
T08 | EF-05 | #ETAT | Rapport complet : état des 4 vannes, pompe, signal GSM, programmations actives, horodatage | Rapport conforme, incluant la liste des programmations actives le cas échéant | Validé

Note méthodologique relative à T06 et T07 : la programmation horaire a été validée en environnement de simulation à l'aide d'une horloge accélérée (1 minute simulée toutes les 3 secondes réelles), permettant d'observer un cycle complet de déclenchement et de fermeture automatiques en quelques dizaines de secondes. En conditions réelles, le firmware s'appuie sur l'horodatage du réseau GSM (commande AT+CCLK?), avec une précision de déclenchement de l'ordre de ±1 minute, cette limite étant documentée dans le cahier des charges (note relative à EF-08).

### 3. Couverture des exigences

Le tableau suivant met en correspondance les exigences du cahier des charges avec les tests réalisés.

ID | Exigence | Test(s) associé(s) | Statut
EF-02 | Commande vannes (ouverture/fermeture) | T02 | Couvert
EF-03 | Commande pompe (démarrage/arrêt) | T04 | Couvert
EF-05 | Rapport d'état complet | T08 | Couvert
EF-08 | Programmation horaire automatique | T06, T07 | Couvert
ES-01 / ES-02 | Contrôle d'accès et rejet des intrus | T03 | Couvert
ES-04 | État sûr au démarrage | T01 | Couvert
ES-05 | Double confirmation arrêt d'urgence | T05 | Couvert
EF-04 | Accusé de réception SMS | T02, T04, T05, T06 | Couvert
ES-03 | Journalisation des tentatives non autorisées | T03 | Couvert
EF-01 / ES-08 | Réception SMS réelle via modem SIM800L, isolation galvanique des relais | — | Non testé en simulation
ES-06 | Watchdog logiciel | — | Non testé en simulation
ES-07 | Protection électrique (diode anti-inversion) | — | Non testé en simulation

Les exigences marquées "Non testé en simulation" nécessitent un environnement matériel réel (modem SIM800L physique, alimentation 12V, circuit de puissance) et seront validées lors de l'intégration sur prototype physique, hors périmètre de cette phase de simulation.

EZZAYRA SOLUTIONS | 2025-2026 | 4

### 4. Limites identifiées

Précision de la programmation horaire (EF-08) : la vérification de l'heure réseau s'effectue toutes les 60 secondes en mode réel, induisant un écart possible de ±1 minute par rapport à l'heure programmée. Un module RTC externe (DS3231) est prévu en version V2 pour lever cette limite.
Tests en environnement de simulation uniquement : les tests présentés dans ce document ont été réalisés en simulation Proteus. Les exigences liées au matériel physique réel (modem GSM effectif, alimentation 12V, isolation galvanique des relais en conditions de charge réelle, watchdog matériel) restent à valider lors de l'intégration sur prototype physique.
Mode de démonstration : les tests ont été exécutés avec le firmware en mode démonstration (MODE_DEMO=true), qui simule la réception SMS par saisie clavier directe plutôt que par décodage réel d'une trame +CMT issue du modem. Le décodage réel du protocole AT (extraction du SMS, gestion des notifications +CMT) a été validé séparément lors du développement, mais n'est pas couvert par les tests T01 à T08 de ce document.

### 5. Conclusion

L'ensemble des huit tests fonctionnels exécutés (T01 à T08) a été validé avec succès, couvrant les exigences fonctionnelles prioritaires (EF-02, EF-03, EF-04, EF-05, EF-08) et les exigences de sécurité critiques (ES-01, ES-02, ES-03, ES-04, ES-05) du cahier des charges.
La fonctionnalité de programmation horaire automatique (#PROG), identifiée comme un point fort du système, a été démontrée de bout en bout : enregistrement de la programmation, déclenchement automatique à l'heure prévue, fermeture automatique après la durée programmée, et annulation sur demande — sans aucune intervention manuelle entre l'enregistrement et l'exécution.
Les exigences nécessitant un environnement matériel réel restent à valider lors de la phase d'intégration sur prototype physique, conformément au périmètre défini dans le cahier des charges.

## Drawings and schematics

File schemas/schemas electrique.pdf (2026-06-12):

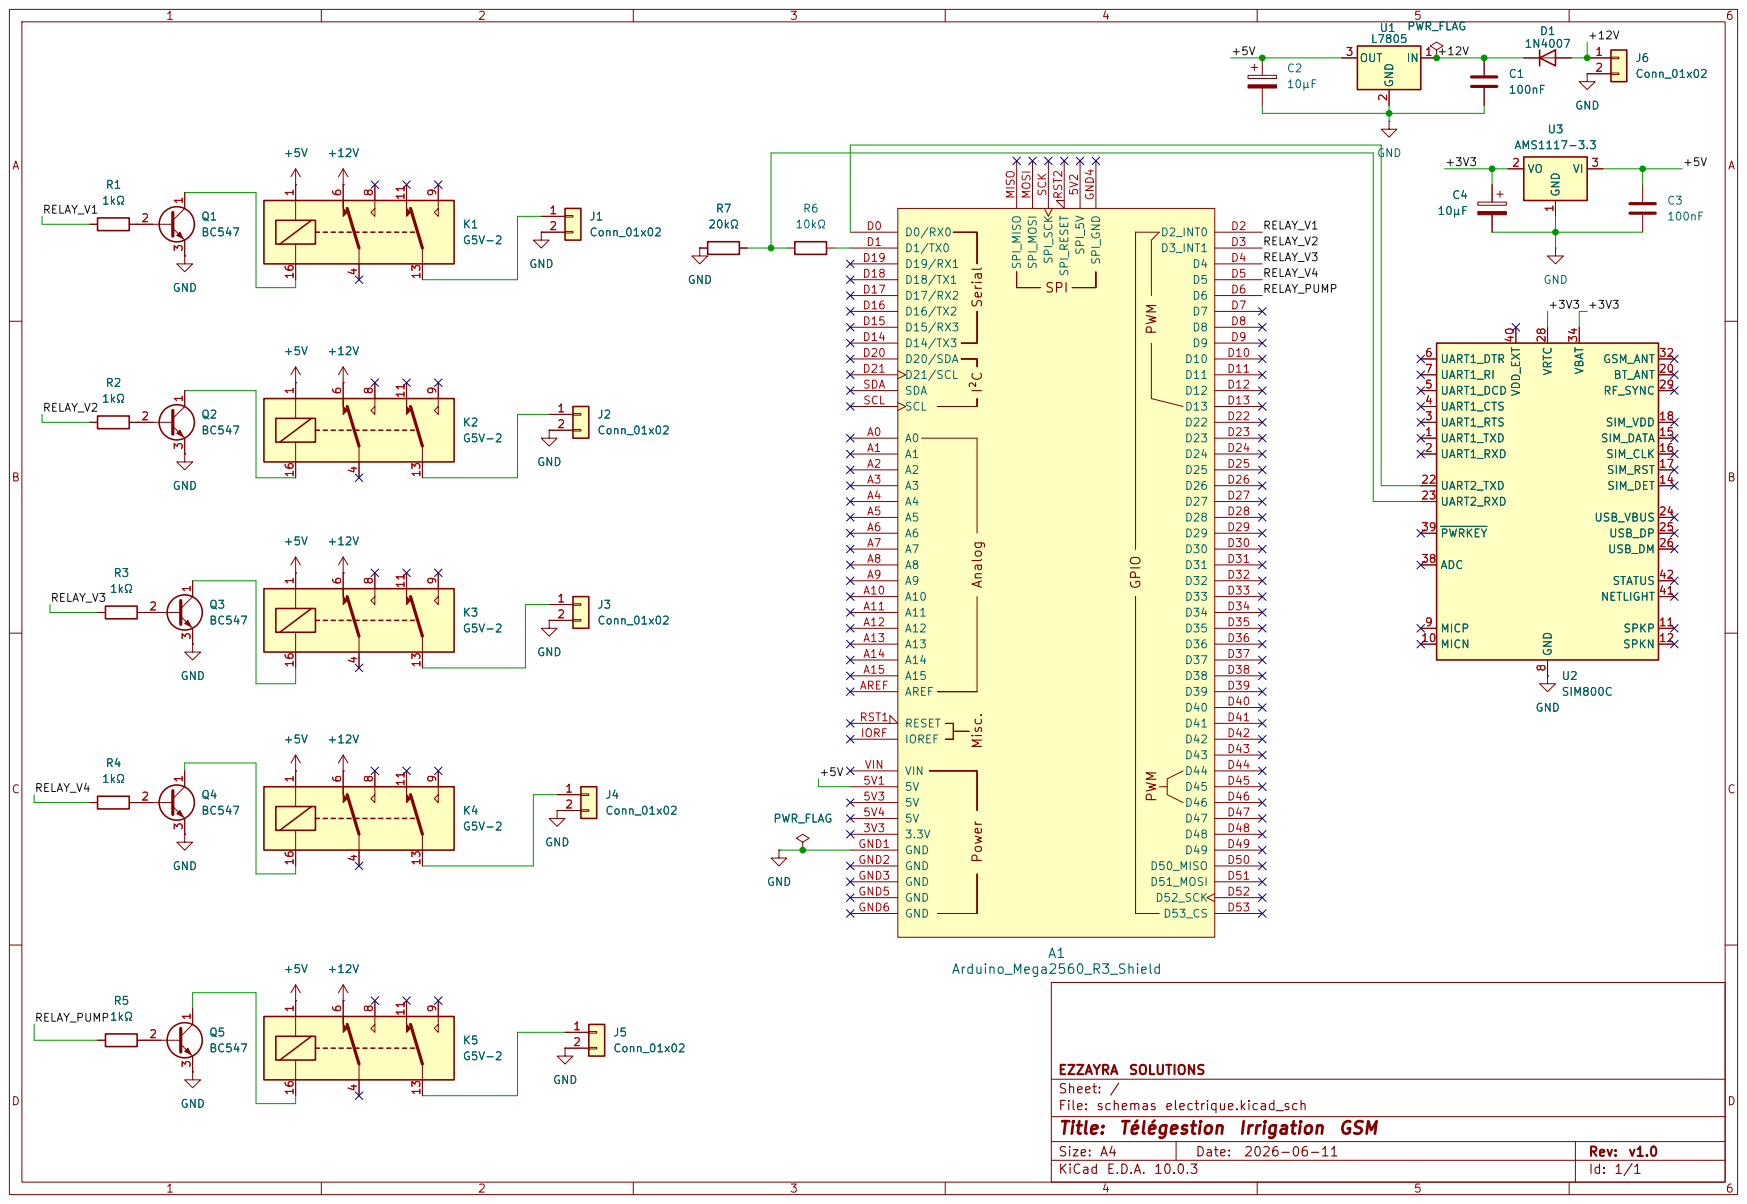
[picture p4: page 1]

GND Serial I²C Analog Misc. Power

EZZAYRA SOLUTIONS
Sheet: /
File: schemas electrique.kicad_sch
Title: Télégestion Irrigation GSM

Size: A4 | Rev: v1.0
KiCad E.D.A. 10.0.3 | Id: 1/1

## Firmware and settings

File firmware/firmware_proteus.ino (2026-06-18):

#include <Arduino.h>
#include <LiquidCrystal.h>
#define MODE_DEMO false

// ─────────────────────────────────────────
//  CONFIGURATION LCD 16x2
//  RS=22, E=23, D4=24, D5=25, D6=26, D7=27
// ─────────────────────────────────────────
LiquidCrystal lcd(22, 23, 24, 25, 26, 27);

// ─────────────────────────────────────────
//  MODEM GSM — Serial1 (TX1=18, RX1=19)
//  Connecté au COMPIM dans Proteus (mode reel uniquement)
// ─────────────────────────────────────────
#define gsm Serial1

// ─────────────────────────────────────────
//  RELAIS — pins adaptées pour Proteus
// ─────────────────────────────────────────
#define RELAY_V1    28
#define RELAY_V2    29
#define RELAY_V3    37
#define RELAY_V4    36
#define RELAY_PUMP  35

#define LED_STATUS  13

// ─────────────────────────────────────────
//  LISTE BLANCHE
// ─────────────────────────────────────────
const int NB_AUTORISES = 3;
String numerosAutorises[NB_AUTORISES] = {
  "+21620123456",
  "+21655987654",
  "+21698111222"
};

// ─────────────────────────────────────────
//  VARIABLES GLOBALES
// ─────────────────────────────────────────
bool stopEnAttente            = false;
unsigned long heureStop       = 0;
int nbTentativesNonAutorisees = 0;
unsigned long totalSecondsPompe = 0;
bool etatVanne[5]  = {false, false, false, false, false};
bool etatPompe     = false;
unsigned long heureDemarragePompe = 0;
unsigned long dernierHeartbeat    = 0;
unsigned long dernierCheckSignal  = 0;
unsigned long dernierCheckProg    = 0;

const unsigned long TIMEOUT_WATCHDOG  = 30000;
const unsigned long DUREE_MAX_POMPE   = 3600000;
const unsigned long INTERVALLE_SIGNAL = 600000;
const unsigned long INTERVALLE_PROG   = 60000;   // mode reel : 60s reelles

// ─────────────────────────────────────────
//  HORLOGE SIMULEE ACCELEREE (MODE_DEMO uniquement)
//  Permet de demontrer #PROG sans attendre une vraie journee.
//  1 minute simulee s'ecoule toutes les VITESSE_DEMO_MS ms reelles.
//  Avec 3000ms -> 1 heure simulee s'ecoule en 3 minutes reelles.
// ─────────────────────────────────────────
const unsigned long VITESSE_DEMO_MS   = 3000;  // ajuster pour filmer plus/moins vite
const unsigned long INTERVALLE_PROG_DEMO = 1000; // verification chaque seconde reelle en demo

int demoHeure   = 6;   // heure simulee de depart (modifiable via #HEURE)
int demoMinute  = 0;
int demoJour    = 1;
unsigned long dernierTickDemo = 0;

// ─────────────────────────────────────────
//  PROGRAMMATION HORAIRE (#PROG)
// ─────────────────────────────────────────
struct Programmation {
  bool active;
  int heure;
  int minute;
  int dureeMin;
  bool enCours;
  unsigned long heureOuverture;
  int dernierJourDeclenche;
};
Programmation prog[5];

// ─────────────────────────────────────────
//  MACHINE À ÉTATS
// ─────────────────────────────────────────
enum Etat { VEILLE, SMS_RECU, VERIFICATION, EXECUTION, REPONSE, ALERTE };
Etat etatActuel = VEILLE;

String numeroExpediteur = "";
String contenuSMS       = "";
String smsBrut          = "";

// ─────────────────────────────────────────
//  DÉCLARATIONS FONCTIONS
// ─────────────────────────────────────────
void toutFermer();
void initialiserModem();
void verifierWatchdog();
void cligneterLED();
void verifierDureePompe();
void verifierSignalGSM();
void verifierProgrammations();
void avancerHorlogeDemo();
void extraireSMS(String smsComplet);
bool numeroAutorise(String numero);
void executerCommande(String cmd);
void journaliser(String numero, String cmd);
void ouvrirVanne(int num);
void fermerVanne(int num);
void demarrerPompe();
void arreterPompe();
void envoyerSMS(String numero, String message);
void envoyerEtat();
void envoyerAlerte(String message);
String envoyerAT(String commande, int attente);
String lireReponseGSM();
String lireHeure();
bool lireHeureActuelle(int &heure, int &minute, int &jour);
void afficherLCD(String ligne1, String ligne2);
void mettreAJourLCD();

// ============================================================
//  SETUP
// ============================================================
void setup() {
  Serial.begin(9600);
  Serial.println("=== EZZAYRA Irrigation GSM - Demarrage ===");

  if (!MODE_DEMO) {
    Serial1.begin(9600);
  }

  pinMode(RELAY_V1,   OUTPUT);
  pinMode(RELAY_V2,   OUTPUT);
  pinMode(RELAY_V3,   OUTPUT);
  pinMode(RELAY_V4,   OUTPUT);
  pinMode(RELAY_PUMP, OUTPUT);
  pinMode(LED_STATUS, OUTPUT);

  lcd.begin(16, 2);
  lcd.clear();
  lcd.setCursor(0, 0);
  lcd.print("EZZAYRA SOLUTIONS");
  lcd.setCursor(0, 1);
  lcd.print("Demarrage...");
  delay(2000);

  toutFermer();
  Serial.println("Securite: toutes les sorties fermees");

  for (int i = 1; i <= 4; i++) {
    prog[i].active = false;
    prog[i].enCours = false;
    prog[i].dernierJourDeclenche = -1;
  }

  afficherLCD("Systeme pret", "Attente SMS...");

  if (!MODE_DEMO) {
    delay(3000);
    initialiserModem();
  } else {
    Serial.println("[DEMO] Mode demonstration actif.");
    Serial.println("[DEMO] Tapez votre commande dans la barre ci-dessus (Ex: #OUVRIR V1)");
    Serial.println("[DEMO] Horloge simulee : 1 min simulee toutes les " +
      String(VITESSE_DEMO_MS) + "ms reelles. Heure de depart : 06:00");
    Serial.println("[DEMO] Utilisez #HEURE hh:mm pour forcer l'heure simulee.");
    numeroExpediteur = "+21620123456"; // Simule que c'est vous l'expediteur autorise
    dernierTickDemo = millis();
  }
  Serial.println("Systeme pret. En attente de commandes SMS...");
  dernierHeartbeat    = millis();
  dernierCheckSignal  = millis();
  dernierCheckProg    = millis();
}

// ============================================================
//  LOOP
// ============================================================
void loop() {
  if (!MODE_DEMO) {
    verifierWatchdog();
    verifierSignalGSM();
  } else {
    avancerHorlogeDemo();
  }

  // verifierProgrammations() tourne dans les 2 modes : en mode reel
  // elle interroge AT+CCLK?, en mode demo elle lit l'horloge simulee.
  verifierProgrammations();

  cligneterLED();
  verifierDureePompe();

  // --- INTERCEPTION DE LA SAISIE CLAVIER (MONITEUR SERIE) EN MODE DEMO ---
  if (MODE_DEMO && Serial.available() > 0) {
    String saisieClavier = Serial.readStringUntil('\n');
    saisieClavier.trim();
    saisieClavier.toUpperCase();

    if (saisieClavier.length() > 0) {
      Serial.println("\n--- [SMS SIMULE RECU] ---");
      Serial.println("Contenu tape : " + saisieClavier);

      // Commande speciale demo : forcer l'heure simulee
      // Format : #HEURE hh:mm  (ex: #HEURE 06:29)
      if (saisieClavier.startsWith("#HEURE ")) {
        String hhmm = saisieClavier.substring(7);
        int posDeuxPt = hhmm.indexOf(':');
        if (posDeuxPt > 0) {
          demoHeure  = hhmm.substring(0, posDeuxPt).toInt();
          demoMinute = hhmm.substring(posDeuxPt + 1).toInt();
          Serial.println("[DEMO] Horloge simulee forcee a " +
            String(demoHeure) + ":" + String(demoMinute));
        }
      } else {
        contenuSMS = saisieClavier;
        afficherLCD("SMS recu:", contenuSMS.substring(0, 16));
        etatActuel = EXECUTION;
      }
    }
  }

  // --- LOGIQUE REELLE DE RECEPTION VIA MODEM GSM ---
  if (!MODE_DEMO && gsm.available()) {
    smsBrut = lireReponseGSM();
    if (smsBrut.indexOf("+CMT:") >= 0) {
      Serial.println("SMS recu !");
      Serial.println(smsBrut);
      etatActuel = SMS_RECU;
    }
  }

  switch (etatActuel) {
    case VEILLE:
      break;

    case SMS_RECU:
      extraireSMS(smsBrut);
      Serial.println("Expediteur : " + numeroExpediteur);
      Serial.println("Contenu    : " + contenuSMS);
      afficherLCD("SMS recu:", contenuSMS.substring(0, 16));
      etatActuel = VERIFICATION;
      break;

    case VERIFICATION:
      if (numeroAutorise(numeroExpediteur)) {
        Serial.println("Numero autorise -> execution");
        etatActuel = EXECUTION;
      } else {
        journaliser(numeroExpediteur, contenuSMS);
        afficherLCD("ACCES REFUSE", numeroExpediteur.substring(0, 16));
        etatActuel = VEILLE;
      }
      break;

    case EXECUTION:
      executerCommande(contenuSMS);
      mettreAJourLCD();
      etatActuel = MODE_DEMO ? VEILLE : REPONSE;
      break;

    case REPONSE:
      envoyerAT("AT+CMGD=1,4", 1000);
      etatActuel = VEILLE;
      break;

    case ALERTE:
      etatActuel = VEILLE;
      break;
  }

  dernierHeartbeat = millis();
}

// ============================================================
//  HORLOGE SIMULEE — avance 1 minute toutes les VITESSE_DEMO_MS
// ============================================================
void avancerHorlogeDemo() {
  if (millis() - dernierTickDemo >= VITESSE_DEMO_MS) {
    dernierTickDemo = millis();
    demoMinute++;
    if (demoMinute >= 60) {
      demoMinute = 0;
      demoHeure++;
      if (demoHeure >= 24) {
        demoHeure = 0;
        demoJour++;
      }
    }
  }
}

// ============================================================
//  LCD — AFFICHAGE
// ============================================================
void afficherLCD(String ligne1, String ligne2) {
  lcd.clear();
  lcd.setCursor(0, 0);
  lcd.print(ligne1.substring(0, 16));
  lcd.setCursor(0, 1);
  lcd.print(ligne2.substring(0, 16));
}

void mettreAJourLCD() {
  // Laisse le message d'action visible 2s avant de revenir a l'etat general
  // (utile pour la vid eo de demonstration)
  delay(2000);
  String ligne1 = "V1:";
  ligne1 += etatVanne[1] ? "O " : "F ";
  ligne1 += "V2:";
  ligne1 += etatVanne[2] ? "O " : "F ";
  ligne1 += "V3:";
  ligne1 += etatVanne[3] ? "O " : "F ";
  ligne1 += "V4:";
  ligne1 += etatVanne[4] ? "O" : "F";

  String ligne2;
  if (MODE_DEMO) {
    // En demo, affiche l'heure simulee a la place de l'etat pompe seul
    ligne2 = "POMPE:" + String(etatPompe ? "ON " : "OFF") + " ";
    if (demoHeure < 10) ligne2 += "0";
    ligne2 += String(demoHeure) + ":";
    if (demoMinute < 10) ligne2 += "0";
    ligne2 += String(demoMinute);
  } else {
    ligne2 = "POMPE:";
    ligne2 += etatPompe ? "ON  " : "OFF ";
    ligne2 += etatPompe ? ">>>" : "---";
  }

  lcd.clear();
  lcd.setCursor(0, 0);
  lcd.print(ligne1);
  lcd.setCursor(0, 1);
  lcd.print(ligne2);
}

// ============================================================
//  INITIALISATION DU MODEM GSM (mode reel uniquement)
// ============================================================
void initialiserModem() {
  Serial.println("Initialisation du modem...");
  afficherLCD("Init modem...", "Attente GSM...");

  int essais = 0;
  while (essais < 10) {
    String rep = envoyerAT("AT", 1000);
    if (rep.indexOf("OK") >= 0) {
      Serial.println("Modem repond : OK");
      afficherLCD("Modem OK", "GSM connecte");
      break;
    }
    essais++;
    delay(1000);
  }

  envoyerAT("AT+CMGF=1", 1000);
  Serial.println("Mode texte active");

  envoyerAT("AT+CSCS=\"GSM\"", 1000);
  envoyerAT("AT+CNMI=2,2,0,0,0", 1000);
  Serial.println("Notifications SMS activees");

  envoyerAT("AT+CMGD=1,4", 2000);
  Serial.println("Anciens SMS supprimes");

  String creg = envoyerAT("AT+CREG?", 1000);
  Serial.println("Reseau: " + creg);

  envoyerSMS(numerosAutorises[0],
    "Systeme irrigation demarre - Pret a recevoir commandes");

  afficherLCD("Systeme pret", "Attente SMS...");
}

// ============================================================
//  COMMANDES AT (mode reel uniquement)
// ============================================================
String envoyerAT(String commande, int attente) {
  if (MODE_DEMO) return "OK";
  gsm.println(commande);
  delay(attente);
  String reponse = "";
  while (gsm.available()) {
    reponse += (char)gsm.read();
  }
  Serial.println("AT >> " + commande);
  Serial.println("AT << " + reponse);
  return reponse;
}

String lireReponseGSM() {
  String reponse = "";
  unsigned long debut = millis();
  while (millis() - debut < 2000) {
    while (gsm.available()) {
      reponse += (char)gsm.read();
    }
  }
  return reponse;
}

// ============================================================
//  EXTRAIRE SMS (mode reel uniquement)
// ============================================================
void extraireSMS(String smsComplet) {
  int posCMT = smsComplet.indexOf("+CMT:");
  int debut  = smsComplet.indexOf("\"", posCMT) + 1;
  int fin    = smsComplet.indexOf("\"", debut);
  if (debut > 6 && fin > debut) {
    numeroExpediteur = smsComplet.substring(debut, fin);
  }

  int rechercheDebutContenu = (fin > 0) ? fin : posCMT;
  int posLF = smsComplet.indexOf('\n', rechercheDebutContenu);
  int posCR = smsComplet.indexOf('\r', rechercheDebutContenu);

  int posFinEntete = -1;
  if (posLF >= 0 && posCR >= 0) {
    posFinEntete = min(posLF, posCR);
  } else if (posLF >= 0) {
    posFinEntete = posLF;
  } else if (posCR >= 0) {
    posFinEntete = posCR;
  }

  if (posFinEntete >= 0) {
    contenuSMS = smsComplet.substring(posFinEntete + 1);
  } else {
    contenuSMS = "";
  }

  contenuSMS.replace("\r", "");
  contenuSMS.replace("\n", "");
  contenuSMS.trim();
  contenuSMS.toUpperCase();
}

// ============================================================
//  LISTE BLANCHE
// ============================================================
bool numeroAutorise(String numero) {
  for (int i = 0; i < NB_AUTORISES; i++) {
    if (numero == numerosAutorises[i]) return true;
  }
  return false;
}

// ============================================================
//  EXÉCUTER COMMANDE
// ============================================================
void executerCommande(String cmd) {
  Serial.println("Execution: " + cmd);

  if (cmd.startsWith("#OUVRIR V")) {
    int numVanne = cmd.charAt(9) - '0';
    if (numVanne >= 1 && numVanne <= 4) {
      ouvrirVanne(numVanne);
      String heure = lireHeure();
      envoyerSMS(numeroExpediteur,
        "Vanne " + String(numVanne) + " ouverte - " + heure);
    } else {
      envoyerSMS(numeroExpediteur, "ERREUR: vanne invalide (1-4)");
    }
  }

  else if (cmd.startsWith("#FERMER V")) {
    int numVanne = cmd.charAt(9) - '0';
    if (numVanne >= 1 && numVanne <= 4) {
      fermerVanne(numVanne);
      String heure = lireHeure();
      envoyerSMS(numeroExpediteur,
        "Vanne " + String(numVanne) + " fermee - " + heure);
    } else {
      envoyerSMS(numeroExpediteur, "ERREUR: vanne invalide (1-4)");
    }
  }

  else if (cmd == "#POMPE ON") {
    demarrerPompe();
    envoyerSMS(numeroExpediteur, "Pompe demarree - " + lireHeure());
  }

  else if (cmd == "#POMPE OFF") {
    arreterPompe();
    envoyerSMS(numeroExpediteur, "Pompe arretee - " + lireHeure());
  }

  else if (cmd == "#ETAT") {
    envoyerEtat();
  }

  else if (cmd == "#STOP") {
    stopEnAttente = true;
    heureStop = millis();
    afficherLCD("STOP demande", "Confirmez...");
    envoyerSMS(numeroExpediteur,
      "ATTENTION: tapez #STOP CONFIRM dans 60s");
  }

  else if (cmd == "#STOP CONFIRM") {
    if (stopEnAttente && millis() - heureStop < 60000) {
      toutFermer();
      stopEnAttente = false;
      afficherLCD("ARRET URGENCE", "Tout ferme!");
      envoyerSMS(numeroExpediteur,
        "ARRET URGENCE execute - " + lireHeure());
    } else {
      envoyerSMS(numeroExpediteur,
        "ERREUR: delai depasse. Renvoyez #STOP");
    }
  }

  // ── #PROG Vx hh:mm duree — programmation horaire reelle ──
  // ── #PROG Vx OFF — annule une programmation existante ──
  else if (cmd.startsWith("#PROG V")) {
    int numV = cmd.charAt(7) - '0';

    if (numV < 1 || numV > 4) {
      envoyerSMS(numeroExpediteur, "ERREUR: vanne invalide (1-4)");
      return;
    }

    String reste = cmd.substring(9);
    reste.trim();

    if (reste == "OFF") {
      prog[numV].active = false;
      prog[numV].enCours = false;
      Serial.println("Prog V" + String(numV) + " annulee");
      envoyerSMS(numeroExpediteur,
        "Programmation V" + String(numV) + " annulee");
      return;
    }

    int posEspace = reste.indexOf(' ');
    if (posEspace < 0) {
      envoyerSMS(numeroExpediteur,
        "ERREUR: format. Exemple: #PROG V1 06:30 20");
      return;
    }

    String hhmm   = reste.substring(0, posEspace);
    int duree     = reste.substring(posEspace + 1).toInt();
    int posDeuxPt = hhmm.indexOf(':');

    if (posDeuxPt < 0 || duree <= 0) {
      envoyerSMS(numeroExpediteur,
        "ERREUR: format. Exemple: #PROG V1 06:30 20");
      return;
    }

    int h = hhmm.substring(0, posDeuxPt).toInt();
    int m = hhmm.substring(posDeuxPt + 1).toInt();

    if (h < 0 || h > 23 || m < 0 || m > 59) {
      envoyerSMS(numeroExpediteur,
        "ERREUR: heure invalide. Exemple: #PROG V1 06:30 20");
      return;
    }

    prog[numV].active = true;
    prog[numV].heure = h;
    prog[numV].minute = m;
    prog[numV].dureeMin = duree;
    prog[numV].enCours = false;
    prog[numV].dernierJourDeclenche = -1;

    Serial.println("Prog V" + String(numV) + " enregistree a " + hhmm +
      " duree " + String(duree) + "min");
    afficherLCD("PROG V" + String(numV) + " OK", hhmm + " " + String(duree) + "min");

    envoyerSMS(numeroExpediteur,
      "Prog V" + String(numV) +
      " enregistree a " + hhmm +
      " duree " + String(duree) +
      "min - sera executee chaque jour. Pour annuler: #PROG V" +
      String(numV) + " OFF");
  }

  else if (cmd == "#AIDE") {
    envoyerSMS(numeroExpediteur,
      "COMMANDES:\n"
      "#OUVRIR V1..V4\n"
      "#FERMER V1..V4\n"
      "#POMPE ON/OFF\n"
      "#PROG Vx hh:mm min\n"
      "#PROG Vx OFF\n"
      "#ETAT\n"
      "#STOP\n"
      "#AIDE");
  }

  else {
    Serial.println("Commande inconnue: " + cmd);
    envoyerSMS(numeroExpediteur, "Commande non reconnue: " + cmd);
  }
}

// ============================================================
//  ENVOYER SMS
// ============================================================
void envoyerSMS(String numero, String message) {
  Serial.println("Envoi SMS a " + numero + " : " + message);
  Serial.println(">>> [SMS ENVOYE A " + numero + "] : " + message);
  if (MODE_DEMO) return;
  gsm.print("AT+CMGS=\"");
  gsm.print(numero);
  gsm.println("\"");

  unsigned long t = millis();
  bool gotPrompt = false;
  while (millis() - t < 5000) {
    if (gsm.available()) {
      char c = gsm.read();
      if (c == '>') { gotPrompt = true; break; }
    }
  }
  if (!gotPrompt) {
    Serial.println("ERREUR: modem ne repond pas au CMGS");
    return;
  }
  gsm.print(message);
  gsm.write(26);
  delay(3000);
  Serial.println("SMS envoye.");
}

// ============================================================
//  ENVOYER ÉTAT
// ============================================================
void envoyerEtat() {
  int niveauSignal = 31;
  if (!MODE_DEMO) {
    String signal = envoyerAT("AT+CSQ", 1000);
    int posCSQ = signal.indexOf("+CSQ: ");
    if (posCSQ >= 0) {
      niveauSignal = signal.substring(posCSQ + 6, posCSQ + 8).toInt();
    }
  }

  String msg = "ETAT SYSTEME:\n";
  msg += "V1:" + String(etatVanne[1] ? "OUVERTE" : "FERMEE") + " ";
  msg += "V2:" + String(etatVanne[2] ? "OUVERTE" : "FERMEE") + "\n";
  msg += "V3:" + String(etatVanne[3] ? "OUVERTE" : "FERMEE") + " ";
  msg += "V4:" + String(etatVanne[4] ? "OUVERTE" : "FERMEE") + "\n";
  msg += "POMPE:" + String(etatPompe ? "ON" : "OFF") + "\n";
  msg += "Signal:" + String(niveauSignal) + "/31\n";
  msg += "Pompe total: " + String(totalSecondsPompe/3600) + "h ";
  msg += String((totalSecondsPompe%3600)/60) + "min\n";

  bool auMoinsUne = false;
  String progMsg = "Prog actives: ";
  for (int i = 1; i <= 4; i++) {
    if (prog[i].active) {
      auMoinsUne = true;
      progMsg += "V" + String(i) + "@";
      if (prog[i].heure < 10) progMsg += "0";
      progMsg += String(prog[i].heure) + ":";
      if (prog[i].minute < 10) progMsg += "0";
      progMsg += String(prog[i].minute) + "(" + String(prog[i].dureeMin) + "min) ";
    }
  }
  msg += auMoinsUne ? progMsg + "\n" : "Prog actives: aucune\n";
  msg += lireHeure();

  if (MODE_DEMO) {
    String heureLCD = (demoHeure < 10 ? "0" : "") + String(demoHeure) + ":" +
                       (demoMinute < 10 ? "0" : "") + String(demoMinute);
    afficherLCD("Signal:" + String(niveauSignal) + "/31", "Heure sim:" + heureLCD);
  } else {
    afficherLCD("Signal:" + String(niveauSignal) + "/31",
                "Pompe:" + String(etatPompe ? "ON" : "OFF"));
  }
  envoyerSMS(numeroExpediteur, msg);
}

// ============================================================
//  ENVOYER ALERTE
// ============================================================
void envoyerAlerte(String message) {
  Serial.println("ALERTE: " + message);
  afficherLCD("ALERTE!", message.substring(0, 16));
  for (int i = 0; i < NB_AUTORISES; i++) {
    envoyerSMS(numerosAutorises[i], "ALERTE: " + message);
    delay(2000);
  }
}

// ============================================================
//  PILOTAGE RELAIS
// ============================================================
void ouvrirVanne(int num) {
  int pins[] = {0, RELAY_V1, RELAY_V2, RELAY_V3, RELAY_V4};
  digitalWrite(pins[num], LOW);
  etatVanne[num] = true;
  Serial.println("Vanne " + String(num) + " OUVERTE");
  afficherLCD("Vanne " + String(num) + " OUVERTE", lireHeure());
}

void fermerVanne(int num) {
  int pins[] = {0, RELAY_V1, RELAY_V2, RELAY_V3, RELAY_V4};
  digitalWrite(pins[num], HIGH);
  etatVanne[num] = false;
  Serial.println("Vanne " + String(num) + " FERMEE");
  afficherLCD("Vanne " + String(num) + " FERMEE", lireHeure());
}

void demarrerPompe() {
  digitalWrite(RELAY_PUMP, LOW);
  etatPompe = true;
  heureDemarragePompe = millis();
  Serial.println("Pompe DEMARREE");
  afficherLCD("Pompe DEMARREE", lireHeure());
}

void arreterPompe() {
  digitalWrite(RELAY_PUMP, HIGH);
  etatPompe = false;
  totalSecondsPompe += (millis() - heureDemarragePompe) / 1000;
  Serial.println("Pompe ARRETEE");
  Serial.println("Total pompe: " + String(totalSecondsPompe/3600) + "h "
    + String((totalSecondsPompe%3600)/60) + "min");
  afficherLCD("Pompe ARRETEE", lireHeure());
}
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

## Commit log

2026-06-08 init: structure projet stage Ezzayra
2026-06-12 feat: schema electrique complet KiCad + PDF - telegestion irrigation GSM
    [schemas electrique.kicad_pcb, schemas electrique.kicad_sch]
2026-06-13 docs: BOM nomenclature composants avec prix fournisseurs tunisiens
2026-06-14 docs: cahier des charges v1 final
2026-06-18 Implementation reelle de #PROG (declenchement et fermeture automatiques), ajout LCD 16x2, alerte signal GSM faible
2026-06-18 Mise a jour cahier des charges v2 : ajout #PROG OFF, note precision PROG, bloc LCD, suppression mentions simulateur Python
2026-06-18 Ajout du projet de simulation Proteus (schema + firmware compile), suppression des anciens simulateurs Python obsoletes
2026-06-18 Ajout du rapport de tests formel (livrable L6) : 8 tests fonctionnels valides, couverture des exigences
